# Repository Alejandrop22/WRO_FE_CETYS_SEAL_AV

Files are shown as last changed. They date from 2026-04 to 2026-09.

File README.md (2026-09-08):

ocean-ezgif com-crop

# WRO_FE_CETYS_SEAL_AV 🪛🦭

World Robot Olympiad - Future Engineers 2026 - CETYS SEAL AV

Systems Engineering Autonomous Labs     S.E.A.L

We are a team made up of 3 second-year engineering students from Mexicali, Baja California, México, excited to participate in Future Engineers for the first time! Our robot, Seal, aims to complete the 2026 future engineers challenges, we look forward to upgrading our prototypes while sharing our journey along the way.

Read our Build-Blog !! Where we document our journey, including our challenges and how we overcame them.      

[April Branch](https://github.com/Alejandrop22/WRO_FE_CETYS_SEAL_AV/tree/version-abril-2026)
[June Branch](https://github.com/Alejandrop22/WRO_FE_CETYS_SEAL_AV/tree/version-junio-2026)

~ Build start date: Monday April 20th, 2026

## Meet the team !! 🫂
<div align="center">


</div>

| |  |  |
|---|---|---|
| Yumián Rodríguez  | Alejandro Pineda  | Jorge Ibarra |
| Studying: Electronic Cybernetics Engineering | Studying: Electronic Cybernetics Engineering | Studying:  Computer Science Engineering |
| Excited to obtain a good placement in the 2026 Future Engineers season.  | Wants to travel to an international championship.  | Ready to work on the prototype day and night. |

We also want to thank our team mentor who has been with us from the start, Luis C. Básaca.



## Robot Overview 🤖 🏎️

Click the preview image below to rotate, zoom, and explore the 3D model for our robot directly in your browser:

Interact with 3D Model (https://sketchfab.com/3d-models/girthy-e7a50c23a9f7431e98fa3d997f9cdc22) 

S.E.A.L.   Dimensions:  Width 10.5cm x  Lenght 17cm x  Height 12.5cm     Weight: 0.4kg

| Top View | Front View | Side View | 
|---|---|---|
| |||

You can find more pictures in our [v-photos
](https://github.com/Alejandrop22/WRO_FE_CETYS_SEAL_AV/tree/main/v-photos) 📸📸

### Components Used ⚡
Find a detailed diagram in [schemes](https://github.com/Alejandrop22/WRO_FE_CETYS_SEAL_AV/tree/main/schemes)

| Component | Model | Quantity | Usage |
|---|---|---|---|
| LipoRiderPlus| Lipo Rider Plus | 1 | Power Distribution |
|LipoBattery| Single Cell 3.7V 1000mAh lipo battery | 1 | Power Supply for all systems |
| ESP32| ESP32 | 1 | Motor |
|ESP32shield| ESP32 Shield | 1 | Power Distribution |
| IMUmpu6050| IMU mpu6050 | 1 | Orientation and Acceleration |
|| Time of Flight Sensor VL53L0X | 1 | Front Sensing |
|| Time of Flight Sensor VL53L1X  | 2 | Wall Sensing |
| H Bridge DR8833| H Bridge DR8833 | 1 | DC Motor Control |
|DC Reduction Motor| DC Reduction Motor | 1 | Movement |
| Steering Servo| Steering Servo | 1 | Steering Direction Control |
| | ESP32 S3 | 1 | Camera Module  |
| | OV3660 3MP 24 Pin | 1 | Camera |
| | BAOTER 3296 Buck Converter | 1 | Voltage Control |

### Electrical Budget ⚡🔋

| Component | Operating Voltage | Typical Current | Peak/Stall Current | Approx. Power (Typ.) |
|---|:---:|:---:|:---:|:---:|
| ESP32 (Motor Control) | 5V (via shield) | 140 mA | ~500 mA (TX) | 0.70 W |
| ESP32-S3 (Camera Module) | 5V (via USB) | 300 mA | ~500 mA (cam) | 1.50 W |
| OV3660 Camera | 3.3V (on-module reg.) | 120 mA | 140 mA | 0.40 W |
| IMU MPU6050 | 3.3–5V | 4 mA | 4 mA | 0.02 W |
| VL53L0X (Front ToF) | 3.3–5V (on-module reg.) | 20 mA | 40 mA (ranging) | 0.10 W |
| VL53L1X ×2 (Wall ToF) | 3.3–5V (on-module reg.) | 20 mA each (40 mA total) | 40 mA each (80 mA total) | 0.20 W |
| DRV8833 (H-Bridge logic) | 5V logic | 2 mA | 2 mA | 0.01 W |
| N20 DC Motor + Gearbox | 5V | 200 mA | ~900 mA (stall) | 1.00 W |
| 9g Steering Servo | 5V | 150 mA | ~700 mA (stall) | 0.75 W |
| **Total (typical driving)** | **5V bus** | **~976 mA** | **~2.9 A (worst-case)** | **~4.9 W** |
| Lipo Battery | 3.7V, 1000 mAh | — | — | 3.7 Wh capacity |
| Lipo Rider Plus (boost) | 3.7V → 5V | ~85–90% eff. | — | — |

**Notes:**
- Values are typical datasheet/estimated figures, not measured 

### Connections Diagram



### Usage Descriptions 🔍🔍
| | | | 
| :--- | :--- | :--- |
| H_Bridge | **H-Bridge** | We were originally powering our h-bridge directly from the esp32 shield, but realized 5V wasn't enough to move our robot fast enough, that's the reason we included our voltage booster, that helps us feed close to 12V into the h-bridge |
| ESP32andSHIELD | **ESP Shield** | We connect all of our components to our ESP32 shield so it can directly control them, thanks to this, we are also able to send 5V power to our IMU straight from the ESP32. We may change our microcrontroller in the future, but as long as we use the ESP32, the shield is of great importance. |
| Lipo | **Lipo Rider and Power Supply** | We connect our 3.7V lipo to the Lipo Rider Plus. With this we power many comments, like the ESP Shield, which connects from a 5V USB A to USB C and our H Bridge connects through 5V and GND pins. The battery life lasts an average of 2 hours per use meanwhile recharging takes around half an hour. We are looking into getting a double cell 7.4V battery which also has more than 1500 mAh. |
| TimeofFlightSensors | **Time of Flight Sensors** | The sensors emit infrared light beams, which helps us read the distance from the robot to the side walls. **When initializing more than 1 sensor, we use the XSHUT pin to asign an id to each one of them, then we add a delay of 100ms between each initialization.** |



## Mechanical Systems ⚙️
Find our material list and step by step instructions on how to build our model in [models](https://github.com/Alejandrop22/WRO_FE_CETYS_SEAL_AV/blob/main/models/README.md)

- Diferential Rear Wheel Drive

| Isometric View | System Description |
|:---|:---|
|| The drivetrain employs a two-stage gear reduction architecture to optimize torque delivery from the N20 motor to the differential. The motor, rated at 1500 RPM, drives a 12-tooth pinion gear that meshes with a 20-tooth primary gear, yielding an initial reduction ratio of 1.67:1. This primary gear is rigidly mounted on an intermediate shaft alongside a secondary 12-tooth pinion, which in turn drives a 36-tooth final gear attached to the differential input shaft. This second stage provides an additional 3:1 reduction, resulting in a combined gear reduction of 5:1 and bringing the differential input speed down to approximately 300 RPM — an ideal balance between wheel torque and maneuverability for the robot's intended operating conditions. |

| Side View | Top View |
|:---:|:---:|
|||

| Component | Teeth | Reduction Ratio |
|:---|:---:|---:|
| Motor Pinion → Primary Gear | 12T → 20T | 1.67:1 |
| Secondary Pinion → Final Gear | 12T → 36T | 3.00:1 |
| **Total Reduction** | — | **5.00:1** |

- Servo Motor Whole Axle Steering

| Isometric View | System Description |
|:---|:---|
|| Steering is handled by a single 9g servo motor that actuates both front wheels through a conventional whole-axle mechanism. Mounted directly above the axle, the servo transmits motion via a LEGO coupling shaft to a central linkage, synchronizing the angle of both wheels for precise turning. This minimalist approach keeps weight low and response times quick, while the LEGO shaft simplifies prototyping and maintenance without sacrificing reliability. |

| Side View | Front View |
|:---:|:---:|
|||

- Modular Double Decker Chasis

| Isometric View | System Description |
|:---|:---|
|| The robot's structural foundation is built around a double-decker LEGO chassis, designed to house electronic components on an elevated upper deck while the drivetrain and steering mechanisms occupy the lower level. This two-tiered configuration was initially adopted as a rapid prototyping solution, allowing the team to prioritize electronics integration and code development during the early stages of the build. However, LEGO's modular nature proved to be more than a temporary fix — it enabled quick on-the-fly adjustments without requiring specialized tools or fabrication, while simultaneously promoting a clean, organized layout for the control electronics. The resulting architecture strikes an effective balance between structural rigidity and accessibility, with the upper deck providing convenient access to sensors, microcontrollers, and wiring, all while maintaining a compact footprint suitable for the robot's intended operational environment. |

| Open Chasis | Side View |
|:---:|:---:|
|||

## Code and Sensing Logic
### Open Challenge

Our code implements an efficient autonomous navigation strategy for the Open Challenge, designed to complete the course reliably in 45–60 seconds. It uses a combination of distance sensors (VL53L1X), an IMU-free approach (no gyro, only encoder), and a state machine that alternates between wall-following and precise 90° turns. The robot first detects an opening to determine its turning direction, then hugs the inner wall, performing exactly 12 turns before stopping and blinking an LED. The state machine is optimized to minimize sensor switching and computation, activating only the necessary sensor per segment. 

#### State Machine
1. BUSCAR_PARED_INICIAL (Initial Wall Search)
2. GIRO_DERECHA / GIRO_IZQUIERDA (Right/Left Turn)
3. SEGUIR_PARED_DERECHA / SEGUIR_PARED_IZQUIERDA (Follow Right/Left Wall)
4. PARAR_BLINKEAR (Stop and Blink)

Some considerations we took while troubleshooting were adding brief stops, so that our servo could allign properly before and after each turn, as well as an added distance travel for when we finish our first and last turns, to make sure we park in the section of the field we started in.

/////////////////  VIDEO DEMO PLACEHOLDER  ///////////////////////

### Obstacle Challenge

For the obstacle challenge, we brought our second esp32 in (esp32s3 n16r8), which hold our ov3660 used to detect the color of the obstacles we encounter. Currently, we're still in the troubleshooting phase for this challenge, and are yet to tackle parking at the end of our run. When our esp in front detects a blob larger than the target size either green or red, we send a signal through two gpio pins so that the other esp can control the robot to move towards the desired path.

#### Decision Flow
1.- Start in the middle lane, and advance forward using Open Challenge logic.
2.- When obstacle encountered, if it's green, follow wall on left, if it's red, follow wall on right.
3.- If outside corner encountered (front sensor < threshold & wall following sensor < threshold), perform 90° turn.
4.- If following wall on any side, and robot detects obstacle that requieres following wall on other side, perform switch.
5.- Try to keep track of laps as best as possible.

/////////////////  VIDEO DEMO PLACEHOLDER  ///////////////////////

## Engineering Decisions Log
### Why LEGO?
We focussed on building a reliable robot that was able to be easily replicated by other teams, we thought of using an existing building base that could help us make quick design changes on the fly (since none of us 3 specialized in CAD) and that's how we ended up choosing LEGO. Some of the key advantages we found that came from choosing this were how easily we could change our transmission gear ratios, find the right pieces that allow movement for both axles, and having a rigid robot structure that has no trouble with integrity or balance issues.



### Sensor Mounts
When we first started our open challenge tests, we realized the VL53L0X sensors weren't showing us the right wall separation distance when we got further away from our target. We thought it was because of our sensor's limitations, and based on troubleshooting we did with different colored walls we found out the black color on the barriers were absorving some of our Time of Flight infrarred light. We switched towared the VL53L1X, which have double the range, 2 meters compared to 4 meters, and we got way better results. At last, our final change was adding a sensor mount that levels both of our ToF sensors on each side, we kept the front sensor as a VL53L0X as we only use it to detect close distances. 

VL53L0X vs VL53L1X

### IMU Changes in Wall Following and Turning with Encoder
At first, we implemented our pid to take the imu values and mix them with the sensor’s readings, this worked to some extent. Eventually, we brought the encoder into the equation, which proved to be more reliable for straight turns. This made us ditch the imu temporally, and we focused on tuning our pid for wall following instead, which gave us the best results overall.

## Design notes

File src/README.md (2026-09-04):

# Source Code
This directory contains all the code and other files used in the process of programming our vehicle.
- In [Obstacle Challenge] you will find the code for both of our esp32 communicating for color detection and obstacle avoidance.
- In [Open Challenge] you will find the code we use to solve every combination of the Open Challenge in complete.
- All the programs used to calibrate or test, we advise a calibration be done whenever you attend a new event, as different walls
and lighting will affect your performance.

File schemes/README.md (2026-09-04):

# Schematics 
This directory contains our schematic diagram which illustrates all the electromechanical components of our vehicle, and how they connect.

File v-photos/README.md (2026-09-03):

## Vehicle Photos 

This directory contains photos of our vehicle during different stages, as well as photos of some of our components.
The [views](https://github.com/Alejandrop22/WRO_FE_CETYS_SEAL_AV/tree/main/v-photos/Views) folder contains the 6 photos of the vehicle from every view.

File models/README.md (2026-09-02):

# MODELS

Here you can find our robot [3d models](https://github.com/Alejandrop22/WRO_FE_CETYS_SEAL_AV/blob/main/models/3d-preview.png), as well as detailed screenshots from our different subsystems. Our build instructions are compressed inside a [zip folder](https://github.com/Alejandrop22/WRO_FE_CETYS_SEAL_AV/blob/main/models/BuildInstructions.zip), 
there you can follow the step-by-step instructions for our build. Clicking on 3d preview will show you a render for our prototype, and clicking on the [stl](https://github.com/Alejandrop22/WRO_FE_CETYS_SEAL_AV/blob/main/models/GIRTHBERT.stl) file will let you visualize an interactive preview, but we recommend using the hyperlink on our main [README](https://github.com/Alejandrop22/WRO_FE_CETYS_SEAL_AV/blob/main/README.md) that takes you to a Sketchfab tab.

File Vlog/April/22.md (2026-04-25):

# April 22nd 2026

It's wednesday now, we are officialy halfway done with our robot in 5  days journey. As for today, we finished calibration of our imu, and implemented it to help our robot mantain orientation while traversing the challenge. We worked more on our electronical organization as well, adding our h bridge and wiring it all together. We're currently facing am issue in which we can't use our dc motor and the servo at the same time, we believe it's because of insufficient current. Tomorrow we will not be able to work on the prototype due to school related activities, but we look forward for our last stretch this friday/saturdauy.

## What we did today

- Electronic Systems
  - Implemented our IMU alongside our time of flight sensor.
  - Took advantage of protoboard floor to connect everything close together.
  - H bridge setup completed, we know it's working correctly because we are able to control the dc motor, it's only when we tried moving the servo that the motor stalls. We were honestly kinda puzzled at this, we tried different approaches to overcome this problem, sucha as changing our wiring, our code, stop using the esp32's power supply, even brought up a capacitor. At the end, we decided to try implementing a current booster, which we will try on friday.

- Coding ! !
  - Began our first all-inclusive code, which connected the servo, IMU, and sensor, to mantain the orientation of our robot.
  - Wrote the algorythm to keep the robot a certain distance away from the wall. Thanks to our PID we were able to tune it on the fly pretty easily, this helped setting up initial test values.

## Day 3 Evidence

Double Decker:

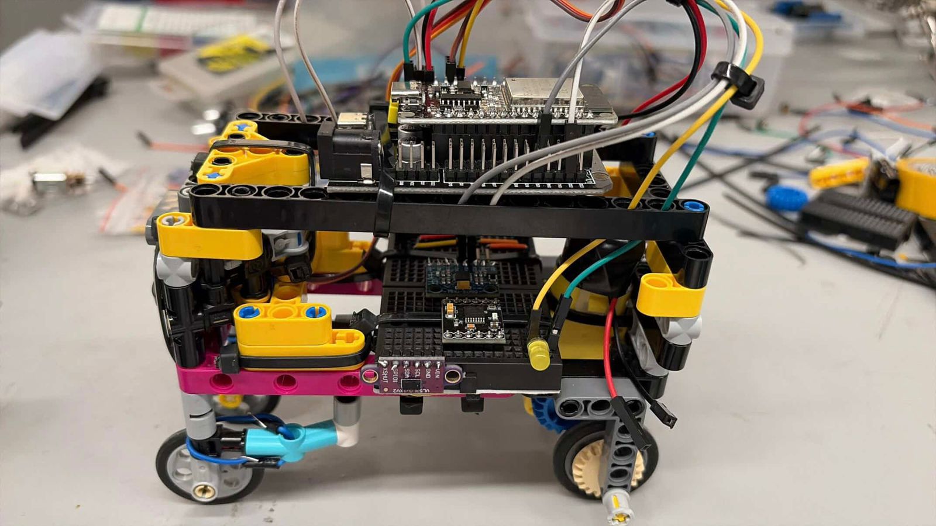
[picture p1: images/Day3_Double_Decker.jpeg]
Double Decker


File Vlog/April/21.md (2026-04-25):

# April 21th 2026

For the second day, we focused on solving some problems we found in yesterday's tests, such as the sensing isues with the ultrasonics (that we won't be using
anymore), setting up an IMU, and finalizing our mechanical systems.

## What we did today

- Mechanical Systems
  - Secured dc and servo motor using zip-ties and lego, (zip-ties are just for keeping in place, none of the lego pieces are actually under hard stress).
  - Re did our servo to lego coupling to avoid the mechanical off-set we had.
  - We realized we didn´t need as much torque as we thought, so we reduced the reduction from approximately 90:1 to a 50:1.

- Electronic Systems
  - Changed our ultrasonic sensors for infrared Time of Flight sensors, we hope to increase our range and obtain better readings.
  - Re did our flooring for our robot, now it's a protoboard floor where we mounted our sensors, this will help with keeping our desing enclosed and save space in the future.
  - Started setup for our IMU, we did off-robot tests and are still working on the filter for the data we need.

## Day 2 evidence

ProtoFloor:

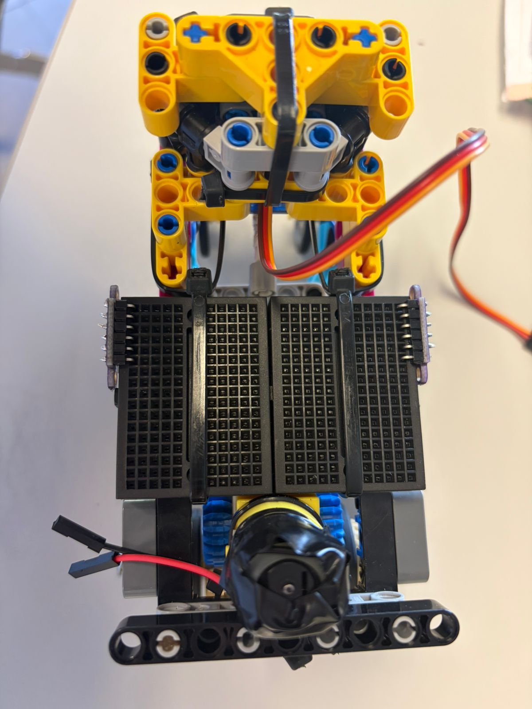
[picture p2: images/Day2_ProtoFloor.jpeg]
Protofloor


ToF Sensor:

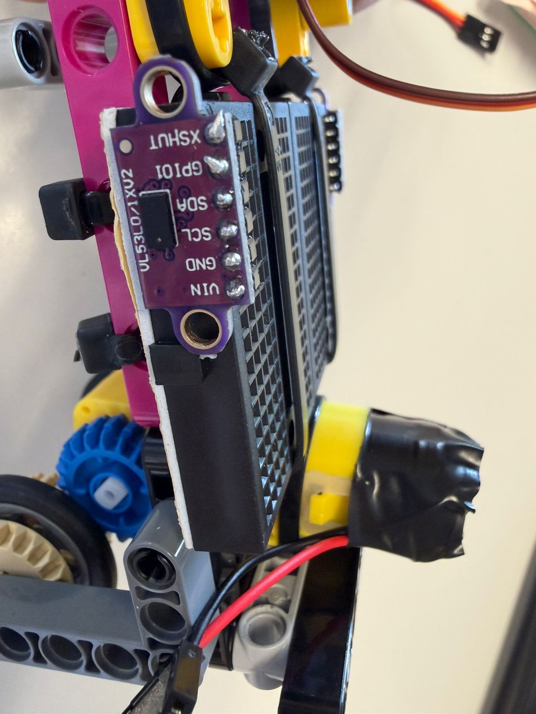
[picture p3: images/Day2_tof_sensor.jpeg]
Sensor


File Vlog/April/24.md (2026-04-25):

# April 24th 2026

Officially our last day to work on the project before the Online Open Championship Qualifier, we are proud to say we have a working robot now!!! (at least for the open challenge that is....) It's actually a little bit sad because had the components we bought had arrived on time we would have at least attempted to program a camera for the SEAL. Even though we faced challenges during our 5 day journey, we are really satisfied with the prototype we were able to develop in such short time. Lastly, we also assembled our field today, which is honestly not great, we printed our own field which we then taped together to build a frankenfield, yes. It's not that bad, but it's really bumpy which is not ideal for our IMU, anyhow, we are close to getting our own official field, which we will use for the Obstacle Challenge and testing later on during the season. Thanks for reading our short blog !!!

## What we did today

- Mechanical Systems
  - It might seem like a small change, but increasing the diameter of our rear wheels makes our robot go way faster, which is crucial for the open challenge. 

- Electronic Systems
  - Today was a loaded day, we solved our h bridge isues after A LOT of trial and error, turns out it was a coding isue.
  - Finished our electronic work for the rest of the challenge, ended up being kind of well organized.
  - Connected our h bridge and ESP Shield to our single cell 1000mAh lipo battery through the lipo rider plus.

- Coding and Tuning
  - We have dedicated most of the day to tuning our PIDS and ideas sensor distances.
  - Added a "slow turn" that lowers the speed of our robot while adjusting for the 90° rotation.

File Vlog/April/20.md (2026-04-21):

# April 20th 2026

We started working on our project today, we will try to post daily updates for the remainder of the time until our first competition, which is the WRO Online Open Championship qualifier for mexican teams. It is currently Monday, April 20th, and we'll have to upload our submission by april 25th I'm pretty sure, so we only have about 5 days to create our robot. At this time, we will focus on completing our drivetrain, troubleshooting our sensors, dedcide which electronic components to use, and hopefully complete the Open Challenge. Depending on the progress we make along the week, we will shift our efforts into tackling the Obstacle Challenge, but our main first objective is completing the Open Challenge.

## What we did today

- Mechanical Systems
  - Initial chasis built out of lego for quick prototyping.
  - Ackerman steering for tight turns.
  - Rear wheel drive assembled with a gearbox reduction. 

- Electronic Systems
  - Troubleshooting with our IMU, motor driver and esp32 to check everything worked correctly.
  - Motor control using H bridge.
  - Direction servo calibrated to our minimun and maximum values for rotation.
  - ESP32 with shield for easier control of our servo and sensors.
  - Verified communication with our ESP32 for quick code iterations.
  - Initialy decided to use ultrasonic sensors, current iteration has them but will be replaced by infrared lidar sensors.
  - Initial PID control for turning at wall detection and trayectory correction.

## First day Evidence

Robot:

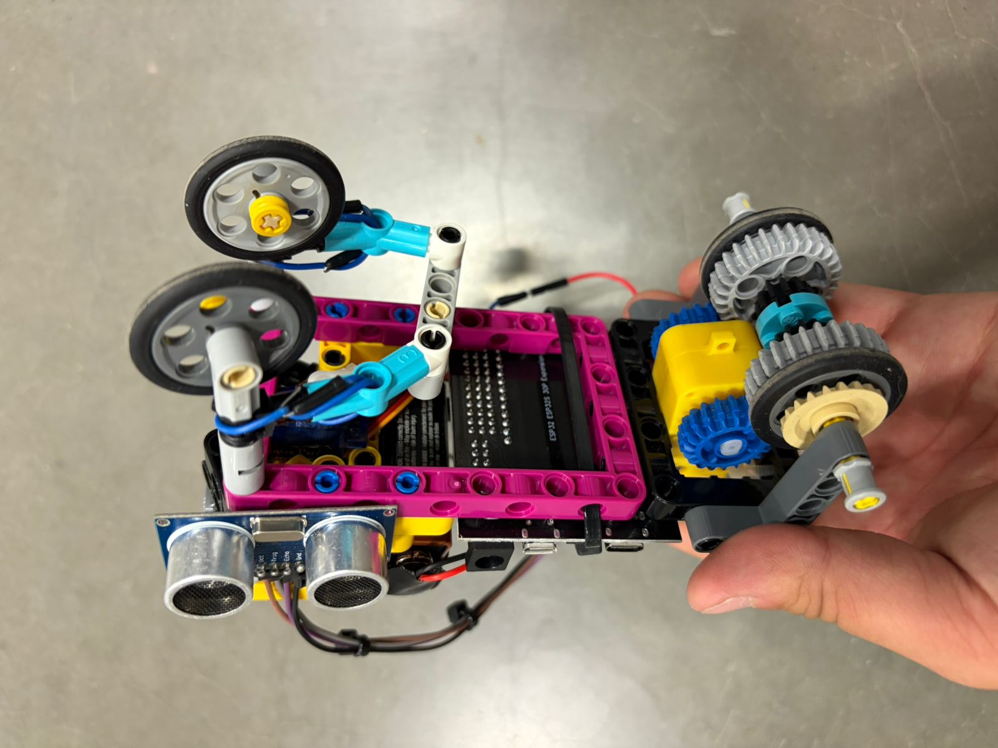
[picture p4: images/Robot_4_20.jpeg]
Vista general del robot


Bottom View:

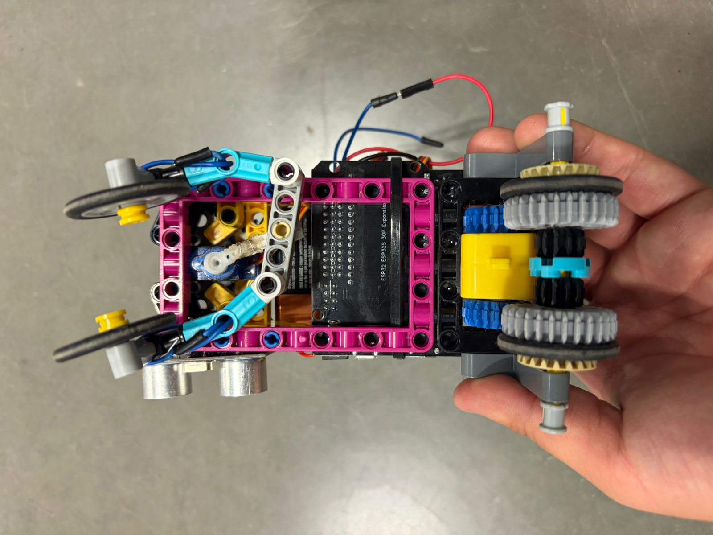
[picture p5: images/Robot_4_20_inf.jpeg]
Vista inferior del robot


Lateral View:

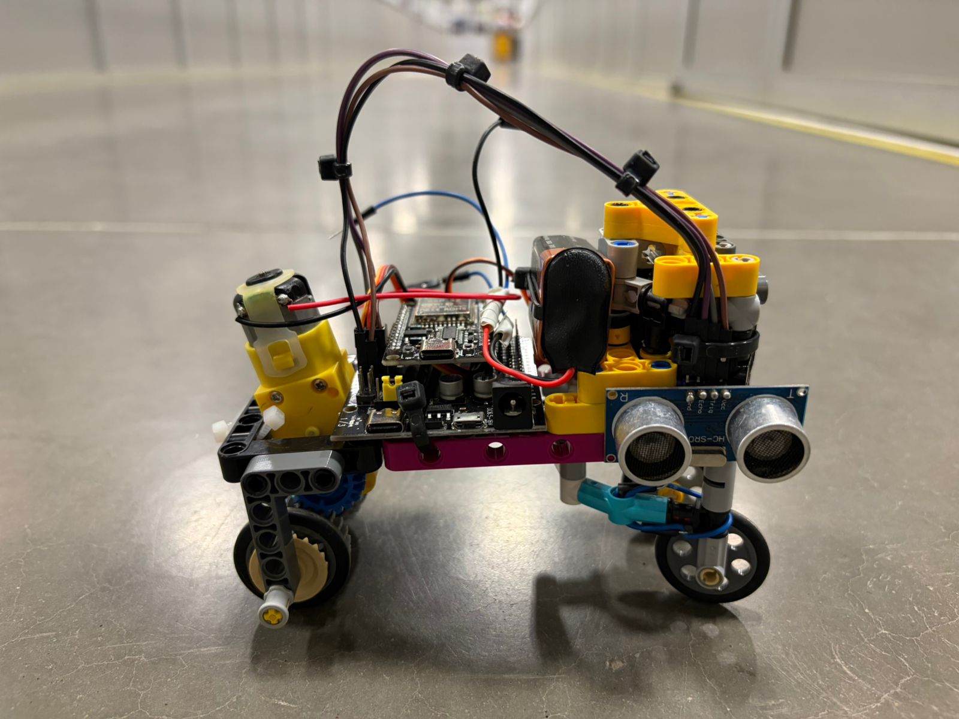
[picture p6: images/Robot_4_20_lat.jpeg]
Vista lateral del robot


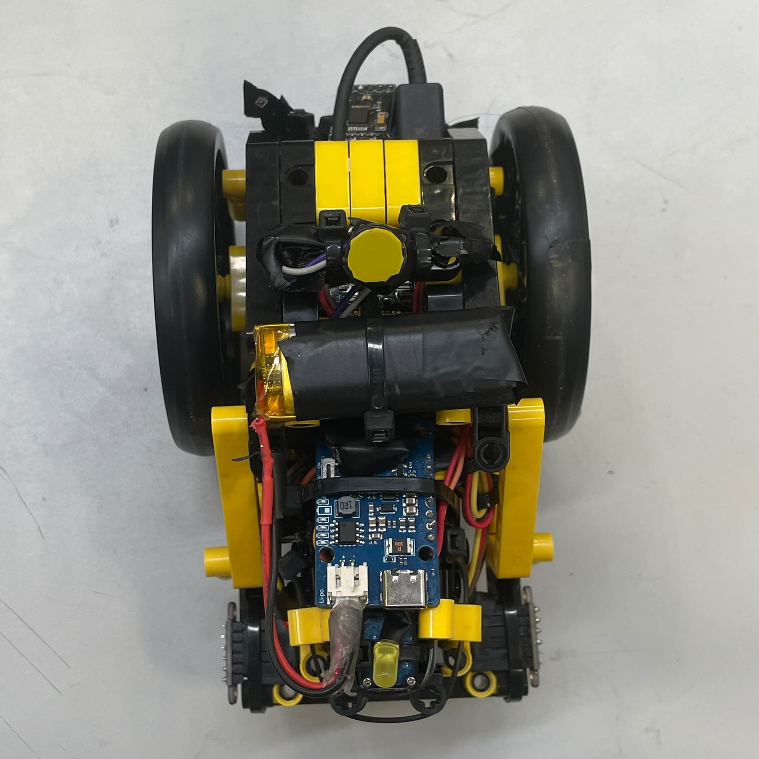
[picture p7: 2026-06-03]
images/TopView.jpeg

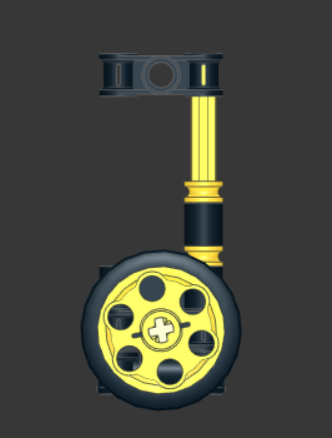
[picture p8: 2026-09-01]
models/servogirthside.png

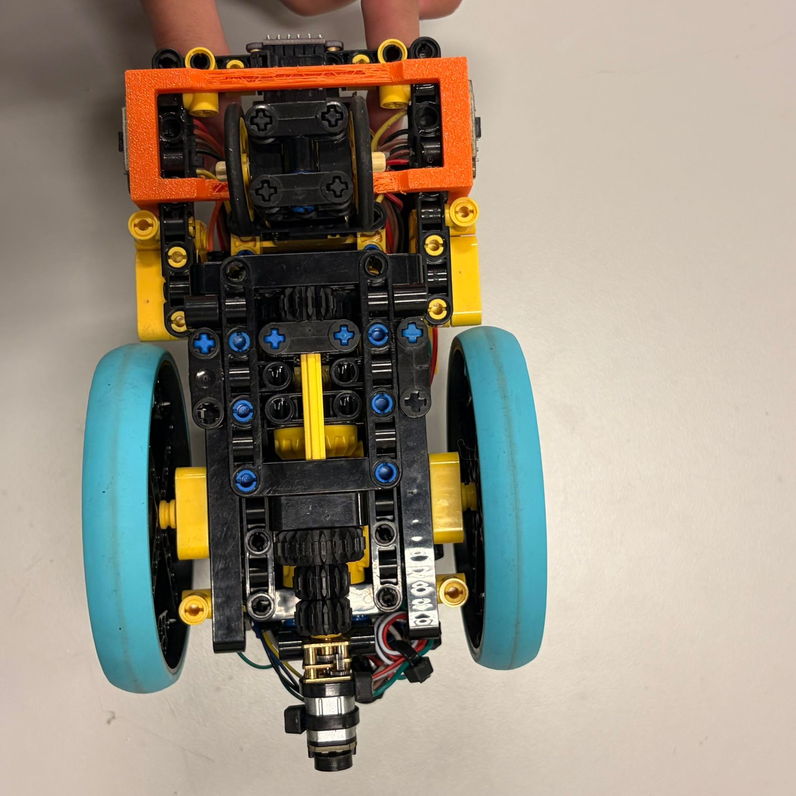
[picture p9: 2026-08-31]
v-photos/Views/BottomView.jpeg

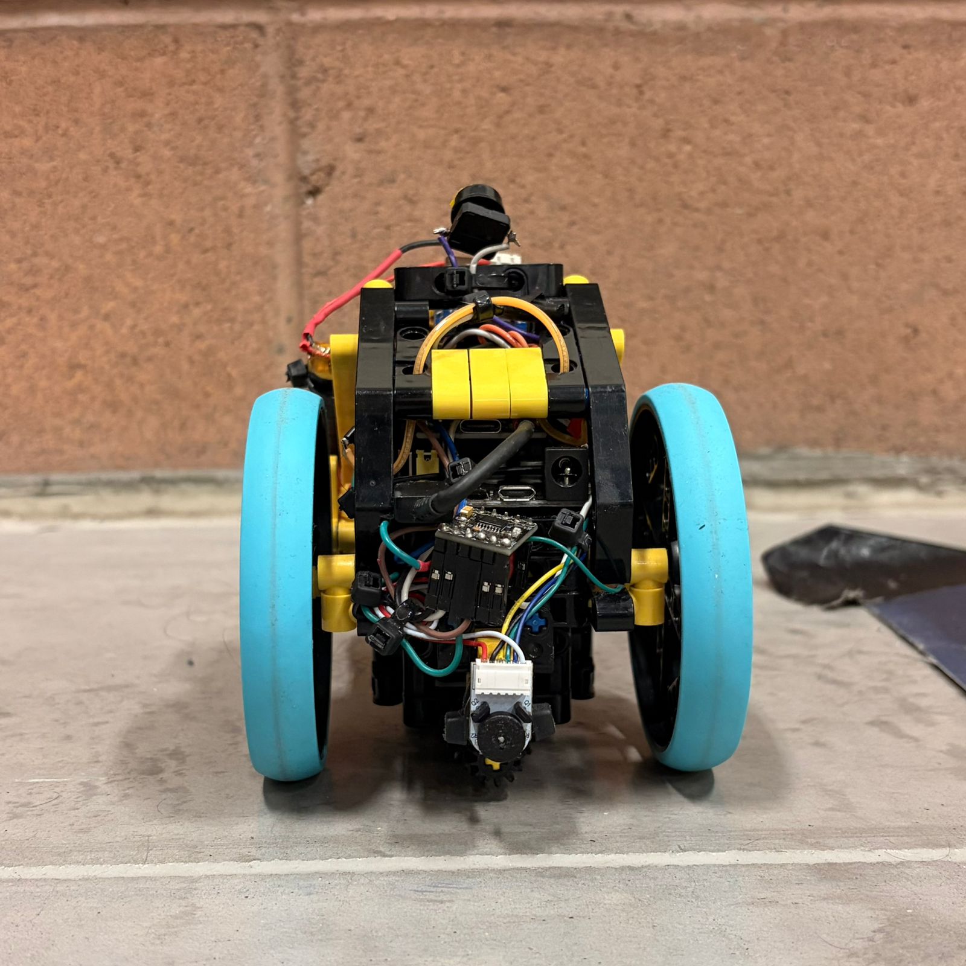
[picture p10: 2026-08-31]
v-photos/Views/BackView.jpeg

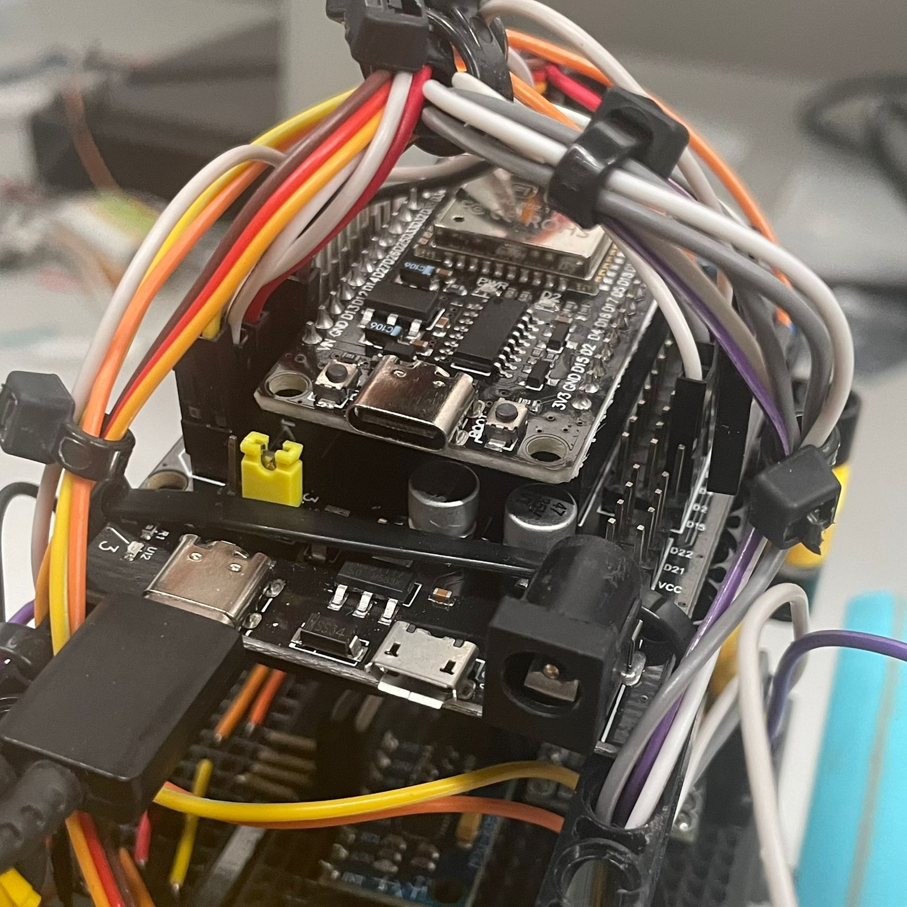
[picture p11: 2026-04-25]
v-photos/ESP32andSHIELD.jpeg

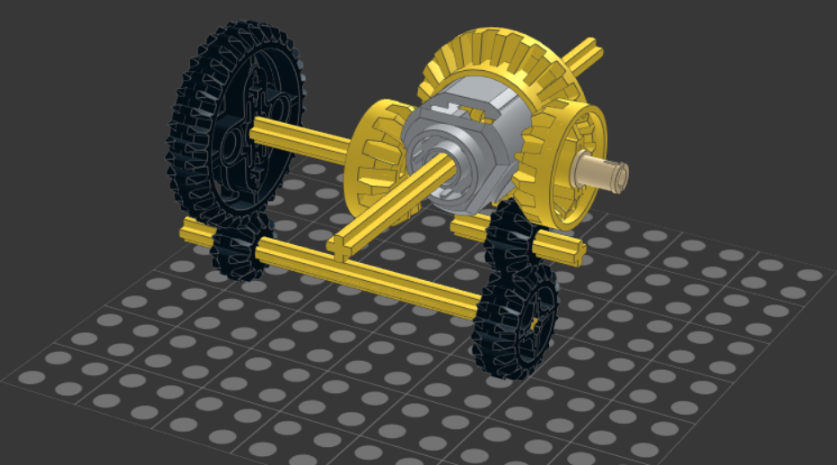
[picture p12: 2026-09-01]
models/isogirthdiff.png

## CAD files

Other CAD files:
models/Cople Pololu-Lego.stl
models/Soporte Vl53l1x lateral.stl
models/GIRTHBERT.stl

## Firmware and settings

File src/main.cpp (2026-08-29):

#include <Arduino.h>
#include <Wire.h>
#include <Adafruit_VL53L1X.h>
#include "soc/soc.h"
#include "soc/rtc_cntl_reg.h"

// ================== PINES ==================
#define XSHUT_RIGHT 15
#define XSHUT_LEFT  13
#define LedPin 18
#define BotonPin 23
#define EncoderPin 19

// ================== OBJETOS ==================
Adafruit_VL53L1X sensor_right = Adafruit_VL53L1X();
Adafruit_VL53L1X sensor_left  = Adafruit_VL53L1X();

// ================== VARIABLES GLOBALES ==================
volatile long encoderCount = 0;

// Direcciones I2C
#define ADDR_S1 0x30   // Sensor derecho
#define ADDR_S2 0x31   // Sensor izquierdo

// Direcciones de movimiento
#define ADELANTE 1
#define ATRAS    2

// Estados de la máquina
enum Estado {
    BUSCAR_PARED_INICIAL,
    SEGUIR_PARED_DERECHA,
    SEGUIR_PARED_IZQUIERDA,
    GIRO_DERECHA,
    GIRO_IZQUIERDA,
    PARAR_BLINKEAR
};

Estado estado = BUSCAR_PARED_INICIAL;

// Contadores y límites
int giroCount = 0;
const int MAX_GIROS = 12;

// Distancias
float forwardAfterCenterCmForCurrentTurn(int currentTurnIndex) {
    if (currentTurnIndex == 0) {
        return 30.0f;
    } else {
        return 5.0f;
    }
}

float turnDistanceCmForCurrentTurn(int currentTurnIndex) {
    if (currentTurnIndex == 0) {
        return 29.0f;
    } else {
        return 25.0f;
    }
}

// Sensores y estado
bool s_right_ok = false;
bool s_left_ok = false;
bool sensorRightActivo = true;
bool sensorLeftActivo  = true;

uint16_t lastDistR = 9999;
uint16_t lastDistL = 9999;
unsigned long lastUpdateR = 0;
unsigned long lastUpdateL = 0;

const unsigned long DATA_STALE_MS = 150;
const unsigned long INTERVALO_LECTURA = 50;
unsigned long ultimaLectura = 0;
const uint16_t UMBRAL_ESQUINA = 200;

// Motor y servo
int MotorPin1 = 2;
int MotorPin2 = 4;
int MotorFrecuency = 5000;
int MotorResolution = 8;

int ServoPin = 25;
int ServoChannel = 2;
int ServoFrequency = 50;
int ServoResolution = 16;
int ServoMin = 60;
int ServoMax = 120;
int SERVO_DUTY_MIN = 1638;
int SERVO_DUTY_MAX = 8191;
int servoCenter = (ServoMin + ServoMax) / 2;
int anguloActual = servoCenter;

const int VELOCIDAD_BASE = 255;
const int VELOCIDAD_SEGUIR = VELOCIDAD_BASE - 30;   // 225

// PID
float Kp = 0.28f;
float Ki = 0.006f;
float Kd = 0.055f;
float pid_integral = 0.0f;
float pid_prev_error = 0.0f;
unsigned long lastPIDTime = 0;
const float INTEGRAL_MAX = 300.0f;

// Búsqueda inicial
unsigned long buscarStartTime = 0;
bool buscarTimerRunning = false;
const unsigned long BUSCAR_TURN_DELAY_MS = 1000;

// Parar y parpadear
bool pararBuscandoTerminado = false;
bool ultimoLadoDerecha = true;

// ================== FUNCIONES ==================
// Interrupción del encoder
void IRAM_ATTR onEncoder() {
    encoderCount++;
}

void resetEncoder() {
    noInterrupts();
    encoderCount = 0;
    interrupts();
}

float getEncoderCentimeters() {
    noInterrupts();
    long val = encoderCount;
    interrupts();
    return (val / 44.0f) * 2.51f;
}

int servoAngleToDuty(int angle) {
    return map(angle, 0, 180, SERVO_DUTY_MIN, SERVO_DUTY_MAX);
}

void moverServo(int angle) {
    ledcWrite(ServoChannel, servoAngleToDuty(angle));
}

void motorVelocity(int velocity, int direction) {
    if (velocity <= 0) {
        ledcWrite(0, 0);
        ledcWrite(1, 0);
        return;
    }

    if (direction == ADELANTE) {
        ledcWrite(0, velocity);
        ledcWrite(1, 0);
    } else {
        ledcWrite(0, 0);
        ledcWrite(1, velocity);
    }
}

void motorStop() {
    ledcWrite(0, 255);
    ledcWrite(1, 255);
}

void activarSensoresParaLado(bool siguiendoDerecha) {
    if (siguiendoDerecha) {
        if (s_left_ok && sensorLeftActivo) {
            sensor_left.stopRanging();
            sensorLeftActivo = false;
            Serial.println("[SENSORES] Izquierdo apagado (siguiendo pared derecha)");
        }
        if (s_right_ok && !sensorRightActivo) {
            sensor_right.startRanging();
            sensorRightActivo = true;
            Serial.println("[SENSORES] Derecho encendido");
        }
    } else {
        if (s_right_ok && sensorRightActivo) {
            sensor_right.stopRanging();
            sensorRightActivo = false;
            Serial.println("[SENSORES] Derecho apagado (siguiendo pared izquierda)");
        }
        if (s_left_ok && !sensorLeftActivo) {
            sensor_left.startRanging();
            sensorLeftActivo = true;
            Serial.println("[SENSORES] Izquierdo encendido");
        }
    }
}

void activarAmbosSensores() {
    if (s_right_ok && !sensorRightActivo) {
        sensor_right.startRanging();
        sensorRightActivo = true;
    }
    if (s_left_ok && !sensorLeftActivo) {
        sensor_left.startRanging();
        sensorLeftActivo = true;
    }
}

void entrarGiroMismoLado(bool siguiendoDerecha) {
    estado = siguiendoDerecha ? GIRO_DERECHA : GIRO_IZQUIERDA;
}

uint16_t leerSensor(Adafruit_VL53L1X &sensor, uint16_t &lastValue, unsigned long &lastUpdate, bool &fresh) {
    if (sensor.dataReady()) {
        int16_t d = sensor.distance();
        sensor.clearInterrupt();
        if (d != -1) {
            lastValue = (uint16_t)d;
            lastUpdate = millis();
        }
    }
    fresh = (millis() - lastUpdate) <= DATA_STALE_MS;
    return lastValue;
}

// ================== SETUP ==================
void setup() {
    WRITE_PERI_REG(RTC_CNTL_BROWN_OUT_REG, 0);
    Serial.begin(115200);
    delay(100);
    Serial.println("[SETUP] Inicio");

    pinMode(LedPin, OUTPUT);

    Wire.begin(17, 16);
    Serial.println("[SETUP] Wire iniciado");

    // Configurar motor y servo
    ledcSetup(0, MotorFrecuency, MotorResolution);
    ledcAttachPin(MotorPin1, 0);
    ledcSetup(1, MotorFrecuency, MotorResolution);
    ledcAttachPin(MotorPin2, 1);
    ledcSetup(ServoChannel, ServoFrequency, ServoResolution);
    ledcAttachPin(ServoPin, ServoChannel);

    pinMode(XSHUT_RIGHT, OUTPUT);
    pinMode(XSHUT_LEFT, OUTPUT);

    pinMode(EncoderPin, INPUT_PULLUP);
    attachInterrupt(digitalPinToInterrupt(EncoderPin), onEncoder, RISING);
    Serial.println("[SETUP] Encoder attached on pin 19");

    // Inicializar sensores VL53L1X
    digitalWrite(XSHUT_RIGHT, LOW);
    digitalWrite(XSHUT_LEFT, LOW);
    delay(20);
    Serial.println("[SETUP] XSHUT ambos LOW");

    // Sensor derecho
    digitalWrite(XSHUT_RIGHT, HIGH);
    delay(50);
    Serial.println("[SETUP] XSHUT derecho HIGH, intentando begin()...");
    if (sensor_right.begin(0x29, &Wire)) {
        Serial.println("[SETUP] sensor_right.begin(0x29) devolvio true");
        sensor_right.VL53L1X_SetI2CAddress(ADDR_S1);
        s_right_ok = sensor_right.begin(ADDR_S1, &Wire);
        Serial.print("[SETUP] sensor_right.begin(readdress) result: "); Serial.println(s_right_ok);
        if (s_right_ok) {
            sensor_right.VL53L1X_SetDistanceMode(3);
            sensor_right.setTimingBudget(140);
            sensor_right.VL53L1X_SetROI(8, 8);
            sensor_right.startRanging();
            sensorRightActivo = true;
            Serial.println("Sensor Derecho OK");
        } else {
            Serial.println("ERROR al reconectar - Sensor Derecho");
        }
    } else {
        Serial.println("ERROR Sensor Derecho (begin)");
    }

    // Sensor izquierdo
    digitalWrite(XSHUT_LEFT, HIGH);
    delay(50);
    Serial.println("[SETUP] XSHUT izquierdo HIGH, intentando begin()...");
    if (sensor_left.begin(0x29, &Wire)) {
        Serial.println("[SETUP] sensor_left.begin(0x29) devolvio true");
        sensor_left.VL53L1X_SetI2CAddress(ADDR_S2);
        s_left_ok = sensor_left.begin(ADDR_S2, &Wire);
        Serial.print("[SETUP] sensor_left.begin(readdress) result: "); Serial.println(s_left_ok);
        if (s_left_ok) {
            sensor_left.VL53L1X_SetDistanceMode(3);
            sensor_left.setTimingBudget(140);
            sensor_left.VL53L1X_SetROI(8, 8);
            sensor_left.startRanging();
            sensorLeftActivo = true;
            Serial.println("Sensor Izquierdo OK");
        } else {
            Serial.println("ERROR al reconectar - Sensor Izquierdo");
        }
    } else {
        Serial.println("ERROR Sensor Izquierdo (begin)");
    }

    moverServo(servoCenter);
    Serial.println("[SETUP] setup completo");

    pinMode(BotonPin, INPUT_PULLUP);
    Serial.println("Presiona el boton para iniciar...");
    Serial.println("[BOTON] GPIO23 configurado como INPUT_PULLUP; conecta el boton entre GPIO23 y GND");

    unsigned long ultimoReporteBoton = 0;
    while (true) {
        int nivelBoton = digitalRead(BotonPin);
        if (nivelBoton == LOW) {
            delay(50);
            if (digitalRead(BotonPin) == LOW) {
                break;
            }
        }
        if (millis() - ultimoReporteBoton >= 1000) {
            ultimoReporteBoton = millis();
            Serial.print("[BOTON] GPIO23 = ");
            Serial.println(nivelBoton == HIGH ? "HIGH (sin pulsar)" : "LOW (pulsado)");
        }
        delay(10);
    }
    Serial.println("Boton pulsado, iniciando...");

    lastPIDTime = millis();
    estado = BUSCAR_PARED_INICIAL;
}

// ================== LOOP ==================
void loop() {
    if (estado == BUSCAR_PARED_INICIAL) {
        activarAmbosSensores();

        if (!buscarTimerRunning) {
            buscarStartTime = millis();
            buscarTimerRunning = true;
            Serial.println("[BUSCAR] Temporizador iniciado (1000 ms)");
        }

        unsigned long tiempoDesdeInicio = millis() - buscarStartTime;
        int velocidadArranque = tiempoDesdeInicio < 500
            ? map(tiempoDesdeInicio, 0, 500, 100, VELOCIDAD_BASE)
            : VELOCIDAD_BASE;
        motorVelocity(velocidadArranque, ADELANTE);

        bool freshL = true, freshR = true;
        uint16_t distL = s_left_ok  ? leerSensor(sensor_left,  lastDistL, lastUpdateL, freshL) : 9999;
        uint16_t distR = s_right_ok ? leerSensor(sensor_right, lastDistR, lastUpdateR, freshR) : 9999;

        Serial.print("Derecha: "); Serial.print(distR);
        Serial.print(freshR ? " mm (OK)" : " mm (CONGELADO/SIN DATOS)");
        Serial.print(" | Izquierda: "); Serial.print(distL);
        Serial.println(freshL ? " mm (OK)" : " mm (CONGELADO/SIN DATOS)");

        bool sensorFrozenLeft = (s_left_ok && !freshL);
        bool sensorFrozenRight = (s_right_ok && !freshR);
        bool sensorCongelado = sensorFrozenLeft || sensorFrozenRight;

        if (sensorCongelado) {
            Serial.print("SENSOR CONGELADO - deteniendo por seguridad. Sensores congelados:");
            if (sensorFrozenLeft) Serial.print(" IZQUIERDO");
            if (sensorFrozenRight) Serial.print(" DERECHO");
            Serial.println();
            digitalWrite(LedPin, HIGH);
            motorStop();
        } else if (distL > 1000 || distR > 1000 || sensorCongelado) {
            Serial.println("No hay pared cercana, deteniendo robot.");
            digitalWrite(LedPin, HIGH);
            motorStop();
            delay(500);
        } else {
            motorVelocity(velocidadArranque, ADELANTE);
            digitalWrite(LedPin, LOW);
        }

        if (sensorFrozenLeft || sensorFrozenRight) {
            if (millis() - buscarStartTime >= BUSCAR_TURN_DELAY_MS) {
                if (sensorFrozenLeft) {
                    estado = GIRO_IZQUIERDA;
                    buscarTimerRunning = false;
                } else if (sensorFrozenRight) {
                    estado = GIRO_DERECHA;
                    buscarTimerRunning = false;
                }
            } else {
                unsigned long remaining = BUSCAR_TURN_DELAY_MS - (millis() - buscarStartTime);
                Serial.print("[BUSCAR] Giro bloqueado por "); Serial.print(remaining); Serial.println(" ms más");
            }
        }
    }

    // ================== BLOQUE DE GIRO ==================
    if (estado == GIRO_DERECHA || estado == GIRO_IZQUIERDA) {
        const bool giroDerecha = estado == GIRO_DERECHA;
        const char *nombreGiro = giroDerecha ? "[GIRO_DERECHA]" : "[GIRO_IZQUIERDA]";

        digitalWrite(LedPin, HIGH);
        motorStop();
        delay(100);

        motorStop();
        delay(200);

        moverServo(giroDerecha ? ServoMax : ServoMin);

        resetEncoder();
        motorVelocity(VELOCIDAD_BASE - 10, ADELANTE);

        Serial.print(nombreGiro);
        float DIST_GIRO_CM = turnDistanceCmForCurrentTurn(giroCount);
        Serial.print(" Girando por encoder hasta ");
        Serial.print(DIST_GIRO_CM);
        Serial.println(" cm...");

        unsigned long turnStart = millis();
        while (getEncoderCentimeters() < DIST_GIRO_CM) {
            if (millis() - turnStart > 5000) {
                Serial.println("[GIRO] Timeout de seguridad, cortando giro");
                break;
            }
            delay(1);
        }

        motorStop();
        delay(100);

        moverServo(servoCenter);
        delay(100);
        motorVelocity(VELOCIDAD_SEGUIR + 10, ADELANTE);
        resetEncoder();

        float distanciaAvance = forwardAfterCenterCmForCurrentTurn(giroCount);
        Serial.print(nombreGiro);
        Serial.print(" Avanzando recto ");
        Serial.print(distanciaAvance);
        Serial.println(" cm");

        while (getEncoderCentimeters() < distanciaAvance) {
            delay(1);
        }

        motorStop();
        delay(1000);

        giroCount++;
        if (giroCount >= MAX_GIROS) {
            Serial.println("[GIRO] Max giros alcanzado, entrando en modo PARAR_BLINKEAR");
            pararBuscandoTerminado = false;
            resetEncoder();
            estado = PARAR_BLINKEAR;
        } else {
            estado = giroDerecha ? SEGUIR_PARED_DERECHA : SEGUIR_PARED_IZQUIERDA;
            ultimoLadoDerecha = giroDerecha;
            activarSensoresParaLado(giroDerecha);
        }
    }

    // ================== SEGUIMIENTO DE PARED ==================
    if (estado == SEGUIR_PARED_DERECHA || estado == SEGUIR_PARED_IZQUIERDA) {
        const bool siguiendoDerecha = estado == SEGUIR_PARED_DERECHA;
        const char *nombreEstado = siguiendoDerecha
            ? "[SEGUIR_PARED_DERECHA]"
            : "[SEGUIR_PARED_IZQUIERDA]";

        digitalWrite(LedPin, LOW);
        motorVelocity(VELOCIDAD_SEGUIR, ADELANTE);

        bool fresh = true;
        uint16_t distancia = siguiendoDerecha
            ? (s_right_ok ? leerSensor(sensor_right, lastDistR, lastUpdateR, fresh) : 9999)
            : (s_left_ok ? leerSensor(sensor_left, lastDistL, lastUpdateL, fresh) : 9999);

        if (!fresh || distancia > 400) {
            Serial.print(nombreEstado);
            if (!fresh) {
                Serial.print(" Sensor ");
                Serial.print(siguiendoDerecha ? "derecho" : "izquierdo");
                Serial.println(" no disponible (CONGELADO). Deteniendo por seguridad.");
            } else {
                Serial.print(" Distancia excesiva: ");
                Serial.print(distancia);
                Serial.println(" mm (>400). Lanzando giro.");
            }
            motorStop();
            delay(50);
            entrarGiroMismoLado(siguiendoDerecha);
        } else {
            unsigned long now = millis();
            float dt = (now - lastPIDTime) / 1000.0f;
            if (dt <= 0) dt = 0.001f;
            lastPIDTime = now;

            const int DESIRED_MM = 100;
            float error = (float)distancia - (float)DESIRED_MM;

            pid_integral += error * dt;
            if (pid_integral > INTEGRAL_MAX) pid_integral = INTEGRAL_MAX;
            if (pid_integral < -INTEGRAL_MAX) pid_integral = -INTEGRAL_MAX;

            float derivada = (error - pid_prev_error) / dt;
            pid_prev_error = error;

            int signoLado = siguiendoDerecha ? 1 : -1;
            int deltaAngle = (int)(signoLado * (Kp * error + Ki * pid_integral + Kd * derivada));

            int newAngle = servoCenter + deltaAngle;
            if (newAngle < ServoMin) newAngle = ServoMin;
            if (newAngle > ServoMax) newAngle = ServoMax;

            moverServo(newAngle);
            anguloActual = newAngle;
            motorVelocity(VELOCIDAD_SEGUIR, ADELANTE);

            Serial.print(nombreEstado);
            Serial.print(" dist="); Serial.print(distancia);
            Serial.print(" mm, servo="); Serial.println(newAngle);
            Serial.print("PID: error="); Serial.print(error);
            Serial.print(", integral="); Serial.print(pid_integral);
            Serial.print(", deriv="); Serial.println(derivada);
            delay(50);
        }
    }

    // ================== PARAR BLINKEAR ==================
    if (estado == PARAR_BLINKEAR) {
        if (!pararBuscandoTerminado) {
            const bool siguiendoDerecha = ultimoLadoDerecha;
            const char *nombreEstado = siguiendoDerecha ? "[PARAR_BLINKEAR_DER]" : "[PARAR_BLINKEAR_IZQ]";

            digitalWrite(LedPin, LOW);
            motorVelocity(VELOCIDAD_SEGUIR, ADELANTE);

            bool fresh = true;
            uint16_t distancia = siguiendoDerecha
                ? (s_right_ok ? leerSensor(sensor_right, lastDistR, lastUpdateR, fresh) : 9999)
                : (s_left_ok ? leerSensor(sensor_left, lastDistL, lastUpdateL, fresh) : 9999);

            if (!fresh) {
                Serial.print(nombreEstado);
                Serial.println(" Sensor no disponible, deteniendo sin completar.");
                motorStop();
                pararBuscandoTerminado = true;
            } else {
                unsigned long now = millis();
                float dt = (now - lastPIDTime) / 1000.0f;
                if (dt <= 0) dt = 0.001f;
                lastPIDTime = now;

                const int DESIRED_MM = 100;
                float error = (float)distancia - (float)DESIRED_MM;

                pid_integral += error * dt;
                if (pid_integral > INTEGRAL_MAX) pid_integral = INTEGRAL_MAX;
                if (pid_integral < -INTEGRAL_MAX) pid_integral = -INTEGRAL_MAX;

                float derivada = (error - pid_prev_error) / dt;
                pid_prev_error = error;

                int signoLado = siguiendoDerecha ? 1 : -1;
                int deltaAngle = (int)(signoLado * (Kp * error + Ki * pid_integral + Kd * derivada));

                int newAngle = servoCenter + deltaAngle;
                if (newAngle < ServoMin) newAngle = ServoMin;
                if (newAngle > ServoMax) newAngle = ServoMax;

                moverServo(newAngle);
                anguloActual = newAngle;
                motorVelocity(VELOCIDAD_SEGUIR, ADELANTE);

                Serial.print(nombreEstado);
                Serial.print(" dist="); Serial.print(distancia);
                Serial.print(" mm, servo="); Serial.println(newAngle);
                Serial.print("PID: error="); Serial.print(error);
                Serial.print(", integral="); Serial.print(pid_integral);
                Serial.print(", deriv="); Serial.println(derivada);
                delay(50);

                if (getEncoderCentimeters() >= 30.0f) {
                    motorStop();
                    pararBuscandoTerminado = true;
                    Serial.println("[PARAR_BLINKEAR] Avance completado, entrando en bucle de parpadeo infinito.");
                }
            }
        } else {
            static unsigned long lastBlink = 0;
            static bool ledState = false;
            unsigned long now = millis();
            if (now - lastBlink >= 500) {
                lastBlink = now;
                ledState = !ledState;
                digitalWrite(LedPin, ledState ? HIGH : LOW);
            }
            delay(10);
        }
    }
}

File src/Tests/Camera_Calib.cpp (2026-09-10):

#include "esp_camera.h"
#include <WiFi.h>
#include "esp_http_server.h"

// =================================================================
// 1. CONFIGURACIÓN RED WIFI
// =================================================================
const char* ssid = "iPhone";
const char* password = "Alejandro123";

// =================================================================
// 2. DEFINICIÓN DE PINES (ESP32-S3 OV3660)
// =================================================================
#define PWDN_GPIO_NUM     -1
#define RESET_GPIO_NUM    -1
#define XCLK_GPIO_NUM     15
#define SIOD_GPIO_NUM      4
#define SIOC_GPIO_NUM      5

#define Y9_GPIO_NUM       16
#define Y8_GPIO_NUM       17
#define Y7_GPIO_NUM       18
#define Y6_GPIO_NUM       12
#define Y5_GPIO_NUM       10
#define Y4_GPIO_NUM        8
#define Y3_GPIO_NUM        9
#define Y2_GPIO_NUM       11
#define VSYNC_GPIO_NUM     6
#define HREF_GPIO_NUM      7
#define PCLK_GPIO_NUM     13

// =================================================================
// 3. INTERFAZ WEB COMPLETA
// =================================================================
static const char PROGMEM INDEX_HTML[] = R"rawliteral(
<!DOCTYPE html>
<html>
<head>
  <meta charset="utf-8">
  <meta name="viewport" content="width=device-width, initial-scale=1">
  <title>ESP32-S3 Detector HSV con Corte de Pista</title>
  <style>
    body { font-family: sans-serif; background: #181825; color: #cdd6f4; text-align: center; margin: 0; padding: 20px; }
    .container { max-width: 800px; margin: 0 auto; background: #1e1e2e; padding: 20px; border-radius: 12px; }
    canvas { width: 100%; height: auto; border-radius: 8px; border: 2px solid #89b4fa; background: #000; }
    .panel { background: #313244; padding: 15px; border-radius: 10px; margin: 15px 0; text-align: left; }
    .control-row { display: flex; align-items: center; justify-content: space-between; margin: 6px 0; }
    .control-row label { width: 45%; font-weight: bold; }
    .control-row input[type=range] { width: 40%; }
    .control-row span { width: 15%; text-align: right; }
    button { background: #89b4fa; color: #1e1e2e; border: none; padding: 12px 20px; font-weight: bold; border-radius: 8px; cursor: pointer; width: 100%; margin: 10px 0; }
    .grid-2 { display: grid; grid-template-columns: 1fr 1fr; gap: 15px; }
    @media (max-width: 600px) { .grid-2 { grid-template-columns: 1fr; } }
  </style>
</head>
<body>
  <div class="container">
    <h2>Detector HSV - Filtro de Pista (ROI Y)</h2>
    <canvas id="canvasDisplay" width="640" height="480"></canvas>

    <!-- CORTADOR DE PISTA -->
    <div class="panel" style="border: 2px solid #74c7ec;">
      <h3 style="color:#74c7ec; margin-top:0;">✂️ Límite de Pista (Ignorar lo de abajo)</h3>
      <div class="control-row">
        <label>Límite Y (Pista %):</label>
        <input type="range" id="roi_y" min="10" max="100" value="45" oninput="updateSliders()">
        <span id="roi_y_val">45%</span>
      </div>
      <small style="color:#a6adc8;">Ajusta el slider hasta que la línea cian punteada quede al final de la pista blanca.</small>
    </div>

    <button id="btnCapturar" onclick="capturar()">📸 Capturar Imagen</button>

    <!-- CONTROLES HSV -->
    <div class="grid-2">
      <!-- VERDE -->
      <div class="panel">
        <h3 style="color:#a6e3a1; margin-top:0;">🟢 Ventana Verde</h3>
        <div class="control-row"><label>H Mín:</label><input type="range" id="gh_min" min="0" max="360" value="55" oninput="updateSliders()"><span id="gh_min_val">55°</span></div>
        <div class="control-row"><label>H Máx:</label><input type="range" id="gh_max" min="0" max="360" value="140" oninput="updateSliders()"><span id="gh_max_val">140°</span></div>
        <div class="control-row"><label>S Mín:</label><input type="range" id="gs_min" min="0" max="100" value="40" oninput="updateSliders()"><span id="gs_min_val">40%</span></div>
        <div class="control-row"><label>S Máx:</label><input type="range" id="gs_max" min="0" max="100" value="100" oninput="updateSliders()"><span id="gs_max_val">100%</span></div>
        <div class="control-row"><label>V Mín:</label><input type="range" id="gv_min" min="0" max="100" value="30" oninput="updateSliders()"><span id="gv_min_val">30%</span></div>
        <div class="control-row"><label>V Máx:</label><input type="range" id="gv_max" min="0" max="100" value="100" oninput="updateSliders()"><span id="gv_max_val">100%</span></div>
      </div>

      <!-- ROJO -->
      <div class="panel">
        <h3 style="color:#f38ba8; margin-top:0;">🔴 Ventana Rojo</h3>
        <div class="control-row"><label>H Mín:</label><input type="range" id="rh_min" min="0" max="360" value="340" oninput="updateSliders()"><span id="rh_min_val">340°</span></div>
        <div class="control-row"><label>H Máx:</label><input type="range" id="rh_max" min="0" max="360" value="1" oninput="updateSliders()"><span id="rh_max_val">1°</span></div>
        <div class="control-row"><label>S Mín:</label><input type="range" id="rs_min" min="0" max="100" value="30" oninput="updateSliders()"><span id="rs_min_val">30%</span></div>
        <div class="control-row"><label>S Máx:</label><input type="range" id="rs_max" min="0" max="100" value="100" oninput="updateSliders()"><span id="rs_max_val">100%</span></div>
        <div class="control-row"><label>V Mín:</label><input type="range" id="rv_min" min="0" max="100" value="25" oninput="updateSliders()"><span id="rv_min_val">25%</span></div>
        <div class="control-row"><label>V Máx:</label><input type="range" id="rv_max" min="0" max="100" value="78" oninput="updateSliders()"><span id="rv_max_val">78%</span></div>
      </div>
    </div>
  </div>

  <script>
    let rawImg = new Image();
    let imgLoaded = false;
    const canvas = document.getElementById('canvasDisplay');
    const ctx = canvas.getContext('2d');

    function capturar() {
      const btn = document.getElementById('btnCapturar');
      btn.disabled = true;
      btn.innerText = 'Capturando...';

      rawImg.crossOrigin = "Anonymous";
      rawImg.src = '/capture?t=' + Date.now();
      rawImg.onload = () => {
        imgLoaded = true;
        btn.disabled = false;
        btn.innerText = '📸 Capturar Imagen';
        processBlobsAndRender();
      };
    }

    function rgbToHsv(r, g, b) {
      r /= 255; g /= 255; b /= 255;
      let max = Math.max(r, g, b), min = Math.min(r, g, b);
      let h, s, v = max;
      let d = max - min;
      s = max === 0 ? 0 : d / max;
      if (max === min) { h = 0; } 
      else {
        switch (max) {
          case r: h = (g - b) / d + (g < b ? 6 : 0); break;
          case g: h = (b - r) / d + 2; break;
          case b: h = (r - g) / d + 4; break;
        }
        h /= 6;
      }
      return { h: Math.round(h * 360), s: Math.round(s * 100), v: Math.round(v * 100) };
    }
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

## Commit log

2026-04-25 Enhance README with documentation evaluation framework
    Added documentation evaluation framework and scoring criteria.
2026-04-25 Corrige gramática y mejora descripción del control del robot
    Se corrigen errores de acentuación y gramática en la sección de 'Coding and Sensors'. Se añade información sobre el control del robot y el flujo del PID.
2026-04-25 Update README with sensor details and calibration info
    Added information about sensors and calibration process.
2026-04-25 Revise electronics and coding sections in README
    Updated sections on electronics and coding, clarified issues with ESP32 and PWM signals, and revised control logic for the robot.
2026-04-26 Add initial robot control code with sensors and motors
2026-04-28 Rename schematic_robot_esp32 (1).svg to schematic.svg
2026-06-03 Revise steering section in README
    Updated steering description and corrected terminology in README.
2026-08-21 Update Time of Flight Sensor details in README
2026-08-21 Update sensor entries in README.md
2026-08-21 Update sensor descriptions in README.md
2026-08-27 Update image sizes in README for camera modules
2026-08-29 Eliminacion de la imu
2026-08-31 Update README with new components and remove duplicates
    Added new components to the README, including ESP32 S3, OV3660 Camera, and BAOTER Buck Converter. Removed duplicate sections for clarity.
2026-08-31 Enhance README with robot overview and sensor info
    Added images and details about the robot's dimensions and sensor initialization process.
2026-09-01 Configure LFS añadir GIRTHBERT STL
    [GIRTHBERT.stl]
2026-09-01 reorganize all files
    [GIRTHBERT.stl]
2026-09-02 Enhance README with hyperlinks for resources
    Updated README to include hyperlinks for 3D models, build instructions, and STL file.
2026-09-04 Agregar esquematico
    [robot_seguidor_pared (2).kicad_sch]
2026-09-04 Create README.md for schematics directory
    Added a README file to explain the schematics directory.
2026-09-04 Add electrical budget section to README
    Added electrical budget section with component details and power consumption estimates.
2026-09-04 Complementear esquematico
    [Esquematico.kicad_sch, robot_seguidor_pared (2).kicad_sch]
2026-09-04 Añadir modelos imprimibles
    [Cople Pololu-Lego.stl, Soporte Vl53l1x lateral.stl]
